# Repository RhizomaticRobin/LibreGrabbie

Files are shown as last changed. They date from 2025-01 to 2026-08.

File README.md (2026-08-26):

# DEXIGRAB

**/ˈdɛk.si.ɡræb/ (DEK-see-grab) - DEXIGRABs (plural): /ˈdɛk.si.ɡræbz/ (DEK-see-grabz)

An advanced, libre-source robot hand with integrated hybrid soft robotics, and soon GelSense-touch capabilities with pretrained sensor fusion RL models

robot hand
robot_hand_back

## Introduction

"What? Another esoteric 3D printed robot hand project that's basically just a toy/puppet/useless gizmo dohicky with 5 string motors? No! There's too many of those already!"

Well, here's where I might change your mind regarding that!

## Features

- **Flexible TPU palm mechanics**, allowing for hybrid soft robotics that allow for actual grasping around curved objects in comparison to current traditional robotic palm mechanics
- 16 motors allowing for **16 DOF hand dexerity**, 3 DOF for each finger and 4 DOF on the thumb
- Straightforward 3D printing and assembly with **only 5-10 3D printed parts** to be assembled together for more plug-and-play use dynamics
- Mechanics and electronics **entirely constrained** inside the palm, allowing for full end-effector modularity with all current and future robotic manipulators
- To utilize a modified L3-F-TOUCH sensing module for the fingers and palm and a stereo raspberry pi camera system for sensor fusion data to train reliable deep reinforcement learning 
- **Universal Robot Attachment** system that can be 3D printed to interface with any robot arm's end effector attachment system
- **Multi-modal sensor fusion** integrating:
  - Intel® RealSense™ Depth Camera D455
  - L3-F-TOUCH sensing for tactile feedback
  - Arduino Pro Mini for motor encoder data collection

## AI & Simulation

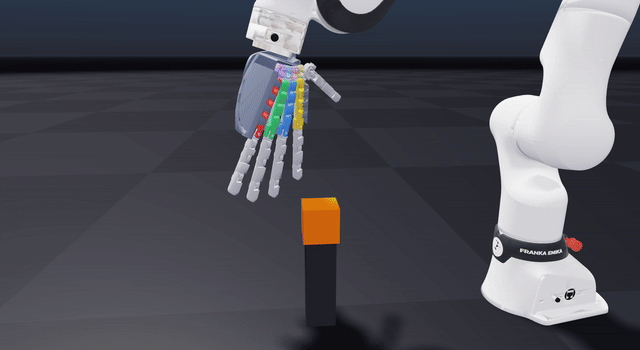
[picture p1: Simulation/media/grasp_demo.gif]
simulated reach -> grasp -> lift with tactile pads


The simulation work now lives in this repo — see [`Simulation/`](Simulation/):

- **Full physics model of the hand in NVIDIA Newton** (MuJoCo-Warp solver): the flexible
  TPU palm modeled as 8 spring palm bones with 3 closed kinematic loops, 22 finger DOFs,
  self-colliding shells, and **15-pad tactile sensing**
- **Arm-mounted grasp demo** (Franka FR3) with an honest `--check` gate — a pass requires a
  clean approach, multi-pad tactile contact, and a real lift, not a cube wedged in the shell
- **GPU-batched in-hand reorientation RL environment** + self-contained PPO trainer,
  validated at **N=8192 parallel worlds, 0.0% solver divergence, ~47k env-steps/s** on a
  single RTX 5090 — plus the full forensics of the batched-solver NaN failure mode that had
  to be root-caused to get there
- **Honest RL status**: reorientation policies stall for contact-fidelity reasons documented
  in [`Simulation/README.md`](Simulation/README.md), so no pretrained models are published
  yet — that finding is what redirected this project toward engine-level contact-physics
  work, rather than shipping policies from a sim that can't be trusted

## Related Resources

- [L3-F-TOUCH shown](https://youtu.be/ASt3WRFcAxU?si=XV7Dn4dw2RqogxgP)
- [General Concept of touch module](https://youtu.be/qtQ4rK66vlE?si=lcGbKkfz59pFsFFY)
- [Simulation environment to be possibly integrated](https://github.com/facebookresearch/tacto)

## Applications

- Primary use as a **robotic end effector** with advanced grasping capabilities
- Secondary application as a **low-weight and cost-accessible hand for prosthetics design**, especially if built with worm drive gearboxes for human-level gripping strength
- Customizable socket system (hopefully also full copyleft) for any given person

## Project Details

- **<$500 cost to build**
- **Fully open source hardware and software** under the GPL 3.0 and CERN-OHL pair license :)

## Coming Soon^TM

- Assembly instructions
- Component lists
- Software setup guide
- Simulation integration details
- Attachment system designs

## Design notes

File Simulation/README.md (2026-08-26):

# Simulation

The DEXIGRAB physics-simulation line: the hand rebuilt as a full articulated model in
[Newton](https://github.com/newton-physics/newton) (NVIDIA's GPU physics engine, MuJoCo-Warp
solver) — flexible palm mechanism and all — with per-pad tactile sensing, an arm-mounted
grasp demo, and a GPU-batched in-hand reorientation RL environment.

reach -> whole-hand grasp -> lift, palm-side view with the 15 tactile pads

*The arm-mounted demo: reach, whole-hand grasp, lift — recorded straight from `newton/flexpalm_arm_demo.py --arm franka --viewer gl` (full quality: [media/grasp_demo.mp4](media/grasp_demo.mp4)).*

This is the simulation work the main README used to promise as "upcoming". It's here now,
including the parts that didn't go the way I wanted (see *Honest status* below).

## What's in here

| Path | What it is |
|---|---|
| [`newton/`](newton/) | All code. Start with [`newton/README.md`](newton/README.md) (hand model + arm grasp demo) and [`newton/README_reorient.md`](newton/README_reorient.md) (batched RL env + the solver-stability findings). |
| [`assets/`](assets/) | The hand CAD as USD (same geometry as `Hardware/`, exported for sim) + the Shell2 recovery re-export. |

Highlights:

- **The hand as a real mechanism, not a rigid prop**: 8 spherical-jointed palm bones with
  tuned spring/damping (the flexible TPU palm), 3 closed kinematic loops, 22 finger DOFs,
  convex-decomposed self-colliding shells.
- **`flexpalm_arm_demo.py`** — reach → whole-hand grasp → lift of a cube on a Franka FR3
  flange, with a 15-pad tactile heatmap. Its `--check` gate only passes a **real grasp**:
  clean approach (the open hand must descend *around* the cube, not through it) + tactile
  contact on ≥2 pads + a >2 cm lift. Lift-only checks are a trap — they green-light a cube
  wedged inside the shell.
- **`flexpalm_reorient_env.py`** — Allegro-style in-hand cube reorientation, GPU-batched
  (one model, one solver, N worlds), 102-D obs including the 15 tactile pad forces,
  validated at **N=8192 with 0.0% solver divergence at ~47k env-steps/s** on one RTX 5090.
- **`train_reorient.py`** — self-contained GPU PPO on that env (rsl_rl `VecEnv`-compatible).
- **`stress_reorient.py`** — the NaN-localization harness that found the solver failure
  modes documented in `README_reorient.md`.

## Requirements

An NVIDIA GPU + a Python env with `newton` (verified on **1.4.0**; the 1.2-era equality API
this was written against is restored by the tiny [`newton/newton_compat.py`](newton/newton_compat.py)
shim), `warp-lang`, `torch`, `usd-core`, `numpy`. Verified on an RTX 5090.

## Honest status

- **What stands**: the mechanism sim, the tactile sensor, the honest-gated grasp demo, and a
  batched env that is *stable at scale* — getting there took root-causing a real solver
  failure (the batched contact + equality solve diverged to NaN in a growing fraction of
  worlds past N≈8; the full forensics, the fix, and the measured tables are in
  [`newton/README_reorient.md`](newton/README_reorient.md)).
- **What didn't work**: dexterous reorientation *policies*. Training runs stall for reasons
  that trace to contact fidelity, not hyperparameters — so no pretrained models are
  published, and I'm not going to ship a policy that only works in a sim I don't trust.
  That result is what pushed this project down the stack, into engine-level work on contact
  physics faithful enough that soft-hand policies trained in sim mean something.

Same licenses as the rest of the repo (GPL-3.0 code; the CAD-derived assets follow the
hardware license).

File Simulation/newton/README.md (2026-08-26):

# flexpalm_hand — flexible robot hand on a Franka *or* Dorna 2 arm (Newton)

A semi-flexible 3D-printed robot hand (8 spherical-jointed palm bones, 5 fingers, convex-
decomposed shell with self-collision) **mounted on a robot arm flange**, performing a
**reach → whole-hand grasp → lift** of a cube, with **per-pad tactile sensing shown as an
in-viewer fingertip heatmap**. Pure Newton + `SolverMuJoCo`, runs in the `isaac` conda env.

Two arms, selected with `--arm` (same hand, mount, grasp logic and tactile for both):
- **`franka`** (default) — Franka FR3 via `add_urdf`.
- **`dorna`** — a **Dorna 2** (5-DOF) with hollow-6xxx-aluminum mass/inertia tuned to the
  real **5.5 kg** arm weight. The Dorna CAD conversion is **not redistributed** in this repo
  (third-party CAD); point `DEXIGRAB_DORNA_USD` at your own USD conversion to enable it.

## Run

```bash
cd Simulation/newton
export LD_LIBRARY_PATH="$CONDA_PREFIX/lib/python3.12/site-packages/nvidia/cu13/lib:${LD_LIBRARY_PATH:-}"   # tactile kernel NVRTC JIT
# headless gate: finalize + reach/grasp/lift, asserts a REAL grasp (clean approach + contact + lift)
python flexpalm_arm_demo.py --arm franka --check
# interactive GL viewer. The viewer steps the full schedule.
python flexpalm_arm_demo.py --arm franka --viewer gl
```

The viewer steps a heavy model (56 bodies, MuJoCo solver + per-frame tactile) at ~0.3x
real-time, so the reach→grasp→lift sequence plays out over a few seconds of wall-clock after
the window opens, then holds the lifted cube.

## Files

| File | Role |
|---|---|
| `flexpalm_arm_demo.py` | **The demo.** Builds the arm (`--arm`) + welds the hand to the flange + a graspable cube on a pedestal; scripted reach/grasp/lift schedule; tactile heatmap recolor; `--check` honest gate. `--viewer gl`. |
| `arms.py` | **Arm builders.** `build_franka` / `build_dorna` → an `ArmSpec` (flange, dofs, ready pose, lift dofs, cube/pedestal defaults). For the Dorna: imports the USD, **re-roots** the articulation at the base (it imports rooted at the flange — inverted), and applies **hollow-aluminum mass/inertia** (`compute_inertia_mesh`, ρ=2700, wall thickness solved for 5.5 kg total). `GRASP_POCKET` + `flange_world_at_ready` place the cube in the hand's rigid rest frame so the grasp transfers between arms. |
| `flexpalm_bones4.py` | The hand builder (`Example`). Body/joint/shell/strip wiring, CoACD self-collision, pose battery. Embeddable: `Example(viewer, args, ext_builder=, attach_body=, attach_xform=, finalize=False)`. Standalone `--viewer gl`/`--check` still work. |
| `hand_taxels_newton.py` | `HandTaxelSensor` — standalone-Newton port of the IsaacLab `_hand_taxels.py` taxel sensor; rasterizes MJWarp per-contact data into per-pad normal force. |
| `franka_show.py` | Helper: spawn the Isaac Franka (Panda) arm in the Kit/PhysX viewer to inspect the flange (run from an IsaacLab checkout: `./isaaclab.sh -p franka_show.py`). |
| `robot_hand_poses.py` | **Vendored** pose battery (`CHAINS`, `JointLookup`, `build_poses`, ...; numpy-only). Copy of the IsaacLab demos file, kept here so the demo is self-contained. `flexpalm_bones4` prefers this local copy. |
| `flexpalm.py`, `flexpalm_spheres.py`, `probe_*.py` | Earlier scaffolding / geometry probes (kept for reference). |

## Assets

- The hand geometry ships in [`../assets/`](../assets): `robot_hand_flexpalm.usda` (working
  copy the builder loads), `robot_hand_simready.usda` (untouched original — the palm cover
  strips are read from here), and the Shell2 recovery re-export. Override the asset root with
  `DEXIGRAB_ASSETS`. The Dorna 2 arm USD is **not** included (see above).

## How the demo works

- **Mount (mechanical mate):** the hand's `cover_back` backplate (at the hand's −X wrist end,
  measured plate normal/center baked into `COVER_BACK_NORMAL`/`COVER_BACK_CENTER`) is seated
  **flat and centered** on the flange face, fingers extending down the tool axis. Computed
  purely in the flange-local frame, so it's independent of the arm pose.
- **Reach → grasp → lift:** arm starts poised above, descends onto the cube, the fingers +
  thumb close on it at the digit **convergence point**, then the shoulder (joint 1) raises to
  lift the cube off the pedestal. A free cube + pedestal keeps grasp forces bounded (stable).
- **Tactile:** `HandTaxelSensor.update()` each frame; `model.shape_color` is rewritten so each
  pad ramps from its base color → yellow → red by contact force (`--force-max` is the
  saturation force).

## Key CLI knobs

`--cube <half_m>` `--cubex/--cubey/--cubez` (cube size/pos — default 6 cm at the finger/thumb
convergence so the **thumb is required**), `--cube-density`, `--grasp-max` (close fraction /
grip firmness), `--force-max` (heatmap saturation N), `--mrz` (palm spin about the wrist axis),
`--mdx/--mdy/--mdz` (seat nudge), `--substeps`/`--iters` (sim speed vs accuracy).

Schedule timing is in `Example._schedule` via `getattr` (settle / approach_dur / close_dur /
hold_dur / lift_dur / lift_amt) — edit there to retune the choreography.

## How the cube is placed (and why the grasp transfers between arms)

The mount mate's shortest-arc rotation lands the hand at a **different roll about the tool axis**
on each flange, so a cube placed at a fixed *flange-local* offset ends up in a different spot
relative to the *hand* — on the Dorna it lands under the palm and gets swallowed. Instead the cube
is placed in the hand's **rigid rest frame** `flange ∘ mount` at a universal `GRASP_POCKET`
derived from the working Franka grasp. That reproduces the same hand-relative grasp on any arm.

For the Dorna, lifting via a single revolute (`dof2`) rotates the hand as it moves, so the
**approach** uses a *small* `lift_amt` (near-vertical, so the open hand descends cleanly **around**
the cube) and the **final lift** uses a larger `lift_raise` (the cube is enclosed by then, so the
tilt is harmless). This is the difference between a real grasp and a cube wedged inside the shell.

## Verified — honest `--check` gate (RTX 5090, `isaac` env, Newton 1.2.0)

`--check` asserts a **REAL GRASP = clean approach + contact + lift**, where:
- **clean approach**: with the hand forced *open*, the descending hand disturbs the resting cube
  by <1.5 cm (i.e. it descends *around* the cube, not *through* it — guards against the cube being
  swallowed by / wedged inside the shell, which a lift-only check cannot see);
- **contact**: tactile fires on ≥2 pads; **lift**: the cube rises >2 cm from grasp to end.

| Arm | mass | approach disturbance | pads (thumb) | cube lifted | REAL GRASP |
|---|---|---|---|---|---|
| `franka` | — | 0 mm | 6 (yes) | +160 mm | **PASS** |
| `dorna` | 5.50 kg (hollow Al, 2.9 mm wall) | 8 mm | 9 (yes) | +129 mm | **PASS** |

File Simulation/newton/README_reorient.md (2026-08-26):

# flexpalm in-hand cube reorientation — batched-Newton RL env

An **Allegro-style in-hand reorientation task** driven by the flexible flexpalm hand **+ its
15-pad tactile sensor**: the hand is fixed palm-up, cradles a free cube, and the policy moves the
22 finger DOFs (PD position targets) to rotate the cube to a randomly sampled target orientation.
Pure Newton + `SolverMuJoCo`, **GPU-batched over N worlds** in one model/one solver, `isaac` env.

Mirrors IsaacLab's `InHandManipulationEnv` (random-quat goal, rotation-distance reward,
success / consecutive-success goal resampling, drop termination) but with our underactuated
closed-loop hand instead of a fully-actuated Allegro/Shadow hand.

## Run

```bash
cd Simulation/newton
export LD_LIBRARY_PATH="$CONDA_PREFIX/lib/python3.12/site-packages/nvidia/cu13/lib"   # tactile NVRTC JIT
python flexpalm_reorient_env.py --check --num-envs 64        # env gate (finite, cube seats, tactile fires)
python stress_reorient.py --mode all --num-envs 1            # solver stress / NaN-localization harness
python train_reorient.py --num-envs 256 --iters 2000         # self-contained GPU PPO
```

## Files
| File | Role |
|---|---|
| `flexpalm_reorient_env.py` | `FlexPalmReorientEnv` — batched build, palm-up cube seating, 22-DOF residual action, 102-dim obs (incl. 15 tactile pad forces), rotation-distance reward, goal resampling, drop termination, NaN-guarded rsl_rl-style VecEnv. `--check` gate. |
| `train_reorient.py` | Self-contained GPU PPO (actor-critic MLP). Env also satisfies the rsl_rl `VecEnv` protocol + returns `{"policy": obs}` from `reset()`, so it drops into rsl_rl `OnPolicyRunner` or liquid-NN `CfCPPO` with no adapter. |
| `stress_reorient.py` | Stress/NaN-localization harness — applies external "tug" wrenches + max-rate finger slew, steps substep-by-substep, reports the first non-finite body/joint + run-up. |
| `hand_taxels_newton.py` | `HandTaxelSensor` — now **batched** (`pad_total[N,15]`, indexed by `con_worldid`); N=1 keeps the original single-world behavior. |
| `flexpalm_bones4.py` | The hand builder (unchanged mechanism); added `simple_shells` collision option (see below). |

## Observation / action / reward

- **obs (102)**: finger pos (unscaled) 22 · finger vel×0.2 22 · cube pos3/quat4/linvel3/angvel3 13 ·
  goal quat 4 · relative quat 4 · **tactile pad forces 15** · prev action 22.
- **action (22)** ∈ [-1,1]: a *residual around the cupped hold pose* (a=0 holds the cube; a=±1 →
  ±0.35 rad), so the stiff hand stays stable and learning starts from a working grasp.
- **reward**: `1/(|rot_dist|+0.1) − 10·goal_dist − 2e-4·Σa² + 250·[rot_dist≤tol] − 50·[dropped]`,
  `rot_dist = 2·asin(‖vec(q_obj·conj(q_goal))‖)`. Consecutive success resamples the goal without
  ending the episode; terminate on drop or timeout.

## The real NaN root cause: the equality SOLVE (use `soft_loops`)

**The definitive fix.** The mitigations below (`shells_jointed`, buffer sizing, substeps, the
NaN-reset guard) reduced but never eliminated the divergence — a long N=8192 run still crept to
~28–31% NaN and collapsed reward. The actual root cause is the **4 MuJoCo equality constraints**
(3 loop closures + shell weld): the equality solve ill-conditions under contact + exploration and
diverges. **`soft_loops=True`** removes all 4 and closes the loops with explicit **penalty-spring
forces** on `body_f` each substep (a Warp kernel between body-local anchors), staying on
SolverMuJoCo (tactile + CUDA graph intact):

| config (N=8192) | env-steps/s | long-run NaN | reward |
|---|---|---|---|
| equality, substeps=4 | 16.8k | **collapsed → 31%** | −4 → −21 |
| equality, substeps=8 | 16k | **crept → 28%** | flat/creep |
| **`soft_loops`, substeps=8** | **47k** | **0.00% (flat, 200 iters)** | −4.7 → −3.2 ✓ |

Removing the equality solve **both eliminates the NaN and runs ~3× faster** (no constraint solve).
Requires **substeps=8**: at substeps=4 the larger dt blows up the explicit springs (NaN → 62%) — an
explicit-integration limit on the light connector proxies. This is now the **trainer default**
(`--soft-loops`, on by default; `--hard-loops` selects the old equality path). Gains
`LOOP_SPRING_KE/KD/FMAX` (1e4 / 1e2 / 300). Convention note: Newton `body_f` is `[force, torque]`
and `body_qd` is `[linear, angular]` — get either wrong and the wrench pumps energy and blows up.

*(A `solver="kamino"` path was attempted — maximal-coordinate, implicit springs — but is **blocked**:
the Newton→kamino `from_newton` bridge can't represent closed loops. Scaffolding kept but inert.)*

## The high-N stability fix (earlier mitigations — superseded by soft_loops as the cure)

The hand is **underactuated + closed-loop + shelled** — unlike the fully-actuated tree-hands
(Allegro/Shadow) the in-hand task was built for. Replicated naively, mujoco-warp's **batched
contact solve diverged to NaN in a growing fraction of worlds above ~8** (N=8 clean, N=256 ~50%).
Ruled out by stress-testing: buffer sizing (real but secondary bugs, fixed), solver config
(Allegro's settings were *worse*), a velocity watchdog (divergence is instantaneous, not a
runaway), and `SolverKamino` (rejects equality constraints → can't run our closed loops). The hand
*alone* was stable at N=256; **the cube vs the hand's ~108 convex collision parts** was the trigger.

**Fix — `shells_jointed` (default ON for this env):** keep the back/bottom shells as **full-
resolution VISUAL meshes** (topology preserved — no convex-blob hack) but take them **out of
collision entirely**, and connect **Shell1↔Shell2 with one explicit equality constraint** — the
chassis hinge the design implied, made explicit so the contact solver never has to mediate the
shells. The shells are the outer chassis (never touch the cube, already self-filtered), so collision
was only ever a liability. **Fingers + palm bones keep full collision (grasp + tactile), visuals are
unchanged, and the underactuated mechanism — D6 spring palm bones, 3 closed loops, 22 finger
revolutes — is untouched.** (`simple_shells`, collapsing each shell to one convex hull, is the
earlier superseded variant; still available.)

**The joint is a CALIBRATED compliant WELD, not a free ball.** A free `connect` (ball-and-socket)
pivots too loosely — it leaves a **27° rotation gap** vs how the shells actually move under the
prior full-CoACD collision. So Shell1↔Shell2 is a `weld` (constrains position **and** orientation,
`torquescale` weighting rotation, `eq_solref` the compliance), and its 5 free parameters — ball
**center (3)** + **torquescale** + **solref time-constant** — are fit to match the reference
CoACD-collision shell trajectory. The fit is done **batched on the GPU**
(`calibrate_shell_ball.py --batched`): each of N worlds gets a *different* candidate weld
(heterogeneous `begin_world`/`add_builder` build), one rollout scores the whole population, and an
evolutionary loop tightens around the elites — **~49k candidates (pop 4096 × 12 gens)** in minutes.

The pivot is **pinned to the shells' fitted mating-sphere center** (where they physically
articulate) by a geometric regularizer (`SHELL_REG=1.0`), then torquescale + solref are fit to the
trajectory: center `(-0.1206, -0.0298, -0.0082)`, torquescale `0.50`, solref_tc `0.099` →
**pos 15 mm / rot 13.5°** against the reference's own ~38 mm shell drift. (Letting the center float
free reaches **5.9 mm / 5.5°** but parks the pivot ~85 mm off the mating surface; we chose the
physically-placed pivot — still far better than the free ball's 27° rotation gap. Drop `SHELL_REG`
to recover the unconstrained fit.)

**Substeps depends on the weld stiffness.** A *stiff* weld (the unconstrained `torquescale 1.54`
fit) needs `substeps=8`: at `substeps=4` it leaves ~8% of worlds diverging under a worst-case probe,
masked by the NaN guard. The **chosen geometric weld is softer (`torquescale 0.50`)** and tolerates
`substeps=4` — only ~0.1% diverge worst-case at N=8192 (5/8192), and PPO trains healthy. The env
class still **defaults to `substeps=8`** (conservative for `--check`/eval and any future stiffer
weld), but **the trainer defaults to `substeps=4`** (the validated, 2×-faster training config).

Also kept as defenses: contact/triangle-pair buffers sized to world count, a NaN-reset guard
(diverged world → `NAN_PENALTY` + reset, logged), a finite-guarded optimizer step (a non-finite
loss/grad never reaches the weights — can't collapse the policy), and a velocity watchdog.

## Scaling + substeps frontier (RTX 5090, short-PPO sweep, geometric weld)

`HEALTHY` = reward improves + max-NaN < 15% + no collapse; `BROKEN` = reward collapsed / NaN runaway.

| N | substeps | tri-pairs/world | max NaN% | env-steps/s | VRAM | verdict |
|---|---|---|---|---|---|---|
| 512 | **2** | 80k | 30.5% | 5323 | — | **BROKEN** (reward → −22) |
| 512 | 4 | 80k | 1.2% | 2749 | — | HEALTHY |
| 512 | 6 | 80k | 1.4% | 2189 | — | HEALTHY |
| 512 | 8 | 80k | 0.0% | 2058 | — | HEALTHY (cleanest) |
| 2048 | 4 | 30k | 2.3% | 5809 | — | HEALTHY |
| 4096 | 4 | 30k | 2.6% | 7207 | 10.8 GB | HEALTHY |
| **8192** | **4** | **15k** | **~2%** | **11083** | **12.4 GB** | **HEALTHY ← default** |
| 4096 | 8 | 30k | 0.03% | 3905 | — | HEALTHY |
| 8192 | 8 | 15k | 0.07% | 5719 | — | HEALTHY |

**Read-off:** substeps floor is **4** (2 collapses); N scales to **8192** with no stability cost
(per-world divergence is N-independent — NaN% stays ~2% regardless of N) and throughput keeps rising
(11k env-steps/s at N=8192/s4). N=8192 fits in **12.4 GB** of 32 GB, but **N=16384 OOM'd** even at
8k tri-pairs/world (one internal buffer alone wanted 11.4 GB) — so 8192 is the practical ceiling at
these buffer sizes; past it needs a different broad-phase strategy (self-pair exclusion), not just a
leaner buffer. (**Superseded:** this frontier was measured on the *equality* path, whose s4 "winner"
actually collapses long-run — see the soft_loops section above; the real winner is `soft_loops`,
substeps=8, ~47k env-steps/s, 0% NaN.) **Equality-path winner: N=8192, substeps=4** — ~2× the substeps=8 throughput, NaN held ~2% by the
guards, training healthy.

**CUDA-graph capture (default on, `use_graph=True`).** The substep physics loop (`_step_sim`:
collide → solver.step → swap → Warp-kernel velocity watchdog — ~90% of per-step launches) is
captured once into a `wp.ScopedCapture` graph and replayed, killing per-launch + Python-loop
overhead. At N=8192/s4: **11.4k → 16.6k env-steps/s (1.46×)**, correct (graph-vs-eager divergence ≤
the eager-vs-eager atomic-nondeterminism baseline) and NaN-rate-neutral. Capturable because the loop
is Warp-only (the watchdog is a Warp kernel, not `torch.clamp_`); reward/done/NaN-guard/reset stay
eager (host syncs, ~10% of launches). Requires **even substeps** (the double-buffer ping-pong lines
up); odd substeps or any capture failure fall back to eager with a **loud banner** — never silent.

## Verified (RTX 5090, isaac, Newton 1.2.0 / mujoco-warp 3.8)

- `--check` N=64: finite, cube seats palm-up at the cup, tactile fires (all envs), cube held under
  random actions, REAL-grasp gate PASS.
- **Stability (`shells_jointed` weld, substeps=8):** N=256 `--check` PASS (finite, peak pad force
  finite — no masked NaN, cube held 98%); worst-case stress probe (uniform-random action/step)
  **0.4% diverged at N=256, 0.2% at N=512** (vs `simple_shells` 2.7%), handled by the reset guard.
  `simple_shells` alone: **N=16…2048 → 0% NaN** under the gentler `--check` actions, held 97–100%.
- **Throughput** (substeps=8): ~1,400 env-steps/s at N=256; scales with N. VRAM ~3 GB at N=256,
  ~14.6 GB at N=2048 (`simple_shells`); the triangle-pair broad-phase buffer is the VRAM bottleneck
  (`_tripairs_per_world` — lean 30k fits N=4096). The batched weld calibration runs pop=4096 at
  ~17 GB.
- **Profiling** (N=2048): the step is ~100% physics — **collision detection ~77%, solver ~23%**,
  everything else (tactile, obs, reward, reset) <0.5% combined. Both run per substep, so substeps is
  the main speed knob — but the calibrated weld needs 8 for stability (see above), so substeps is not
  free here. The remaining big lever is cutting collision broad-phase work (excluding hand-self
  candidate pairs / lower-vert finger hulls).
- **Training: PPO learns** — in the first iterations the drop rate falls and reward rises as the
  policy learns to hold + manipulate the cube. Full reorientation (success rate up) needs long runs,
  as for any in-hand task.

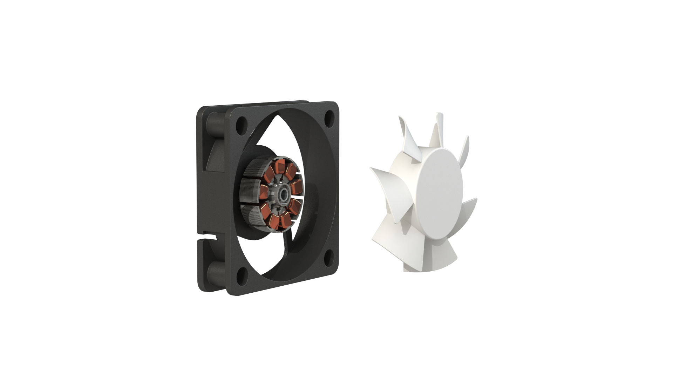
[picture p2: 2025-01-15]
Hardware/Biomemetic Robot Hand, Prosthetic/MiniFan/Renderings/Exploded.png

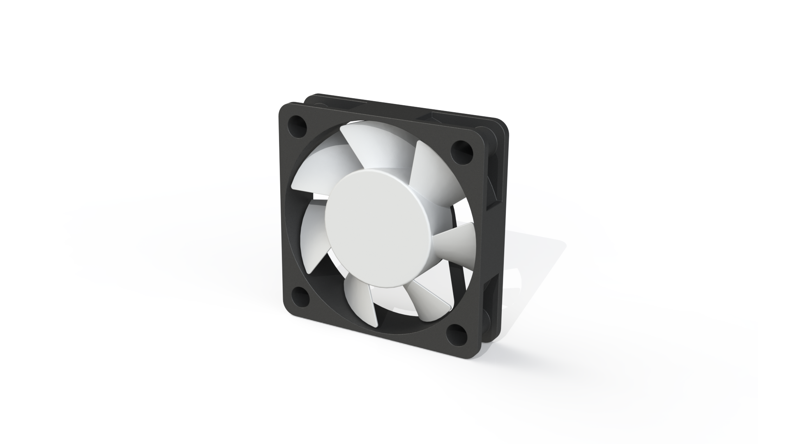
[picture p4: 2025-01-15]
Hardware/Biomemetic Robot Hand, Prosthetic/MiniFan/Renderings/TiltedIsometric.png

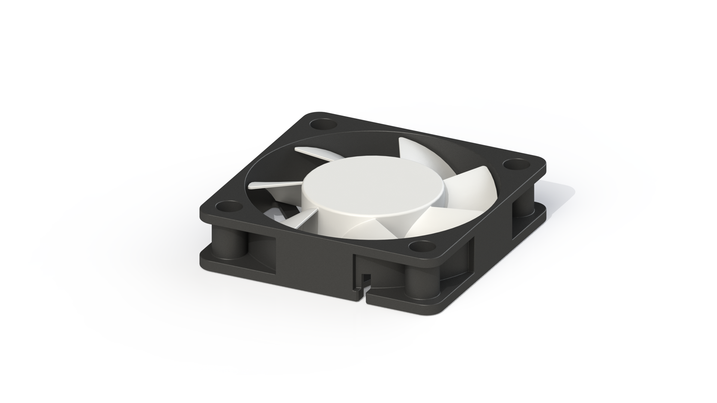
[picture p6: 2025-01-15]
Hardware/Biomemetic Robot Hand, Prosthetic/MiniFan/Renderings/Resting.png

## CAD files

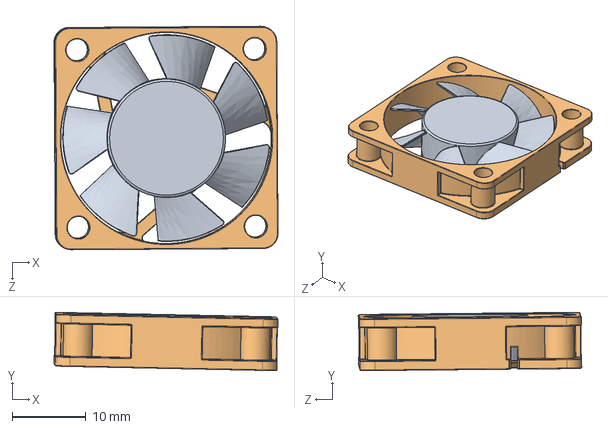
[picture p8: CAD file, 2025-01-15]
Hardware/Biomemetic Robot Hand, Prosthetic/MiniFan/final_assembly.SLDASM
30.3 x 7.87 x 30.2 mm
RotorBlades
MotorHouse

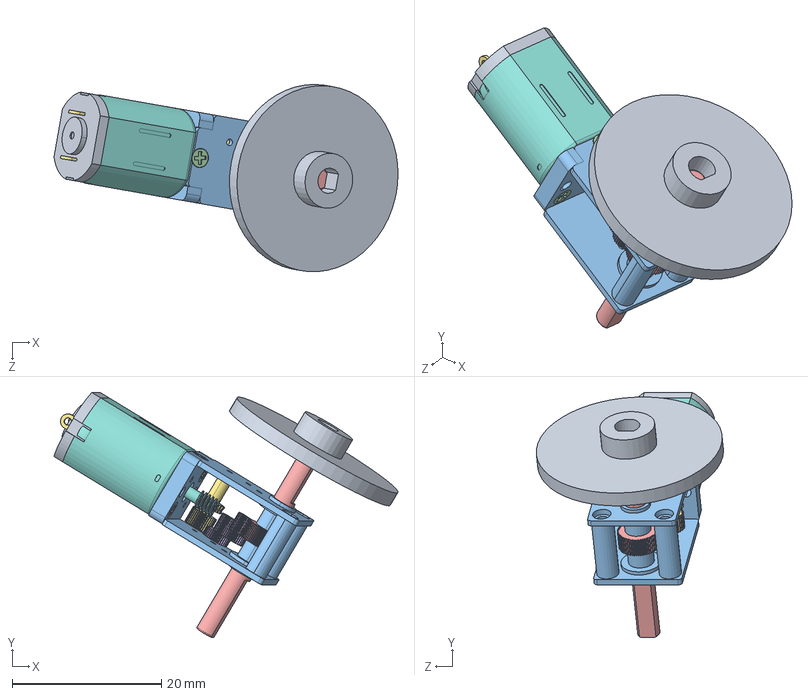
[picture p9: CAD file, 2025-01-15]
Hardware/Biomemetic Robot Hand, Prosthetic/Assem1.SLDASM
46.1 x 32.8 x 25.1 mm
____________.STEP
____.STEP
______.STEP
____-0.STEP
__________.STEP
____-1.STEP
____-2.STEP x 2
________.STEP
__.STEP
________-3.STEP
__________-4.STEP
____________-5.STEP x 4
Engrenagem reta28-D.STEP
Engrenagem reta22-11.STEP x 2
WHEEL.STEP
WORM.STEP
hand_pulley_wheel1

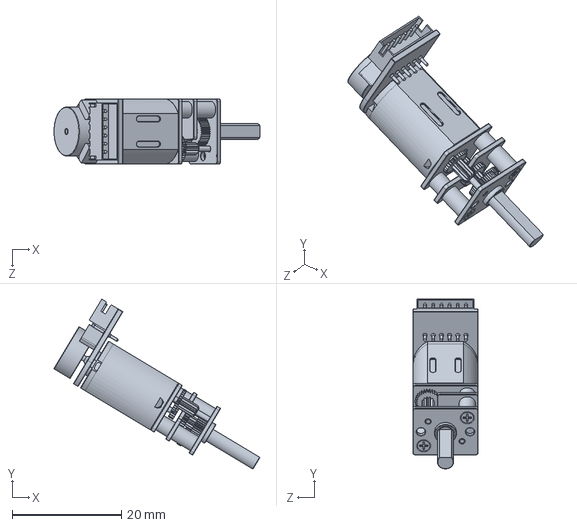
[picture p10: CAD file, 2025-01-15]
Hardware/Biomemetic Robot Hand, Prosthetic/motor_cav.SLDASM
37.8 x 31.1 x 12.0 mm

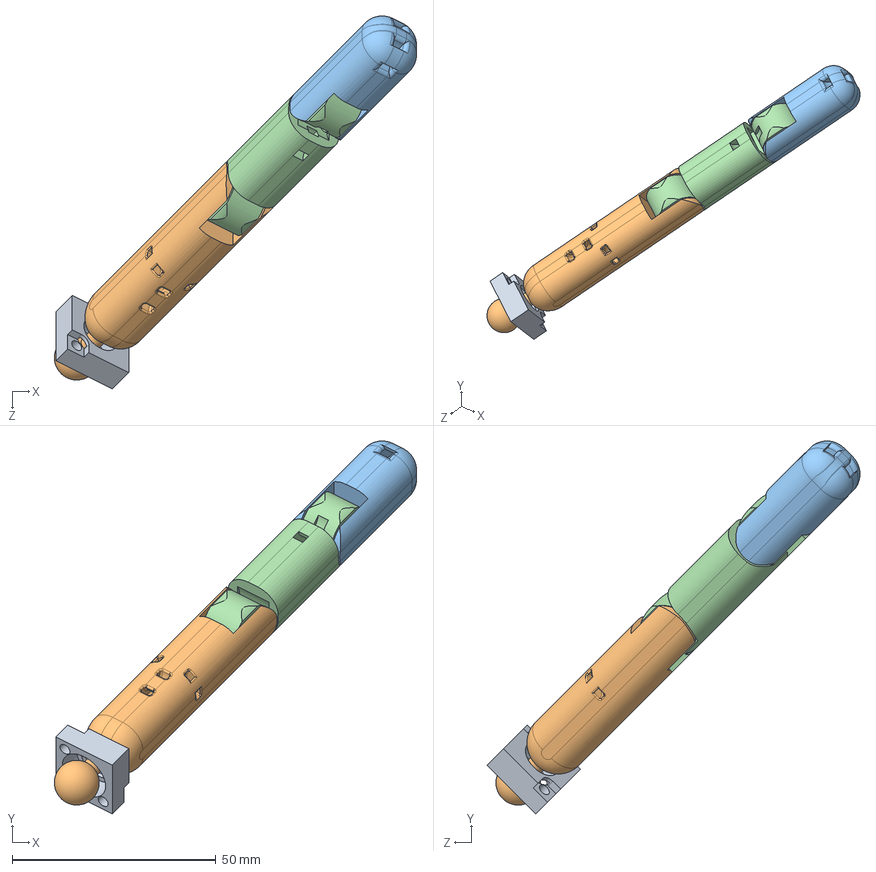
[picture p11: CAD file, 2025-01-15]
Hardware/Biomemetic Robot Hand, Prosthetic/thumb_assembly.SLDASM
88.9 x 91.6 x 91.6 mm
thumb_ball_joint_cap
Metacarpal Bone_V02_thumb
Distal Phalanx Bone_V02
Proximal Phalanx Bone_V02

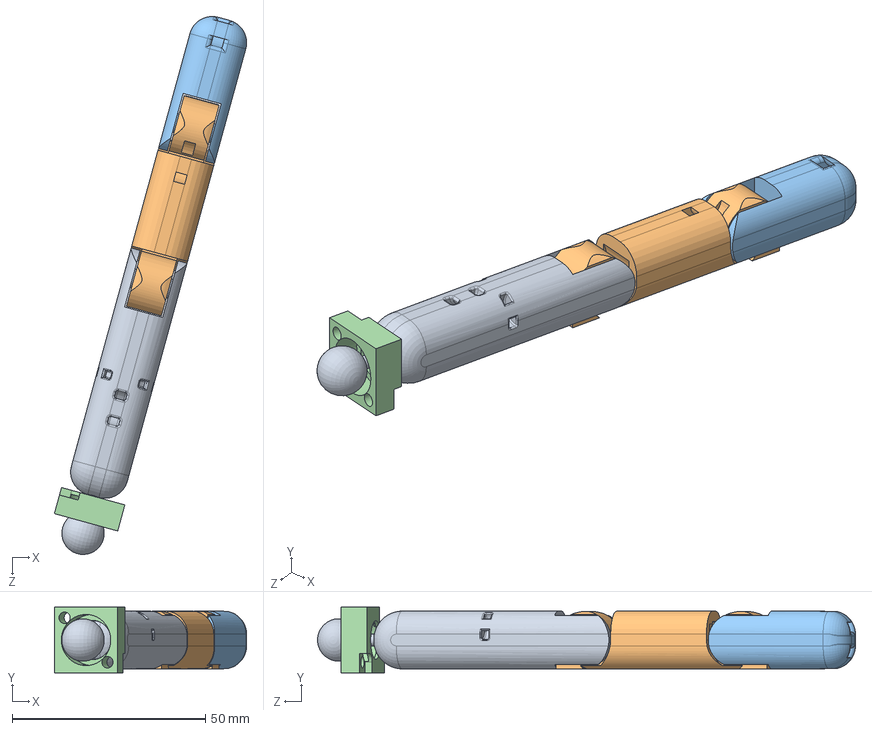
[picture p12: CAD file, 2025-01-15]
Hardware/Biomemetic Robot Hand, Prosthetic/thumb_printable.SLDASM
49.8 x 17.0 x 139.2 mm
Metacarpal Bone_V02_thumb
Proximal Phalanx Bone_V02
Distal Phalanx Bone_V02
thumb_ball_joint_cap

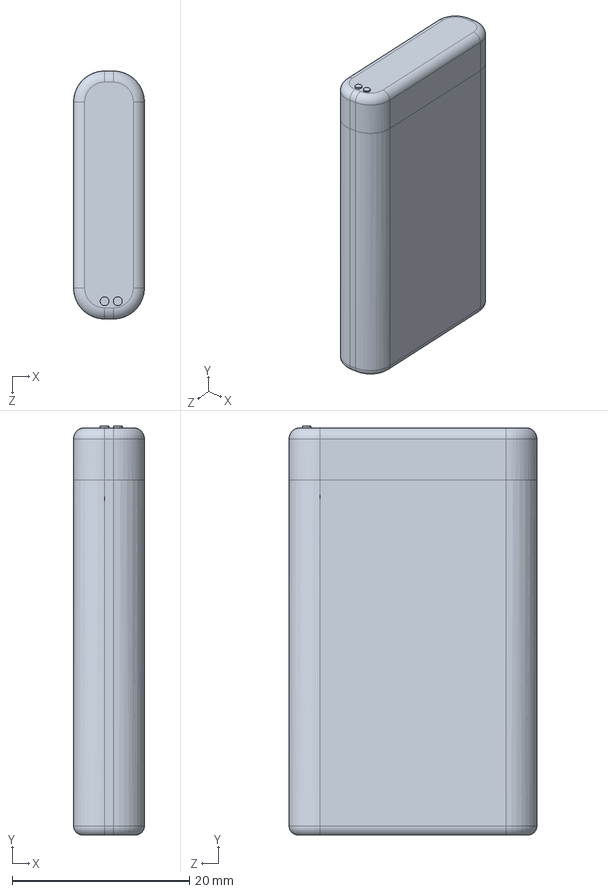
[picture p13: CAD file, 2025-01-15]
Hardware/Biomemetic Robot Hand, Prosthetic/battery_tolerance_shell_ass.SLDASM
8.00 x 46.2 x 28.0 mm

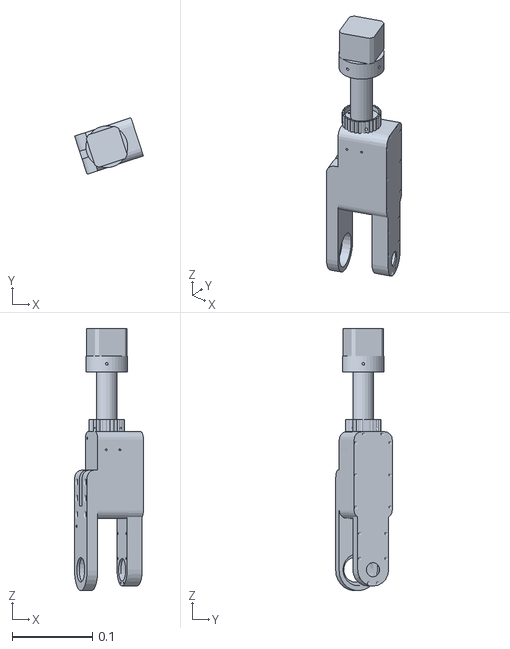
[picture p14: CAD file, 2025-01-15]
Hardware/Biomemetic Robot Hand, Prosthetic/ROS_AR2_urdf-master/meshes/link_4.STL
0.0856 x 0.0704 x 0.326

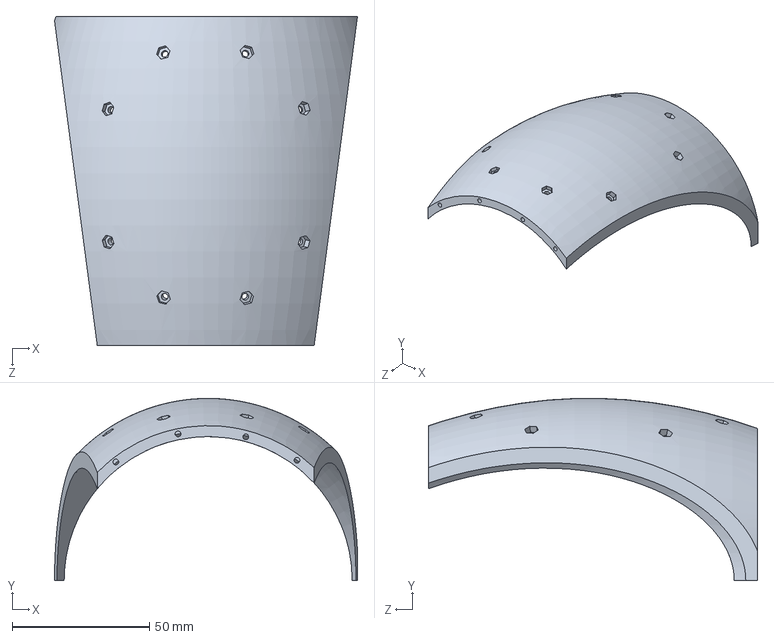
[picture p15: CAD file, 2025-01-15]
Hardware/Biomemetic Robot Hand, Prosthetic/Shell1.SLDPRT
110.5 x 66.4 x 120.0 mm

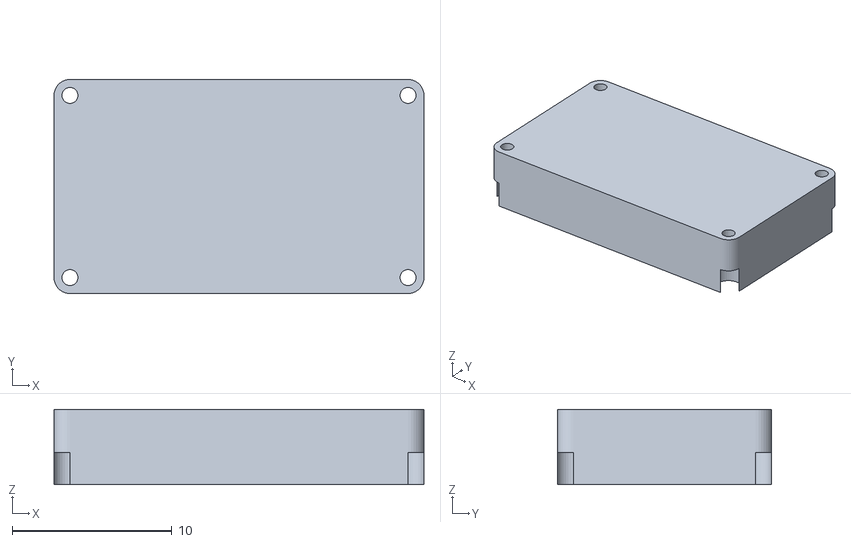
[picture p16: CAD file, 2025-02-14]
L3-F-TOUCH-master/prototype/Acrylicsheet.stl
23.2 x 13.4 x 4.70

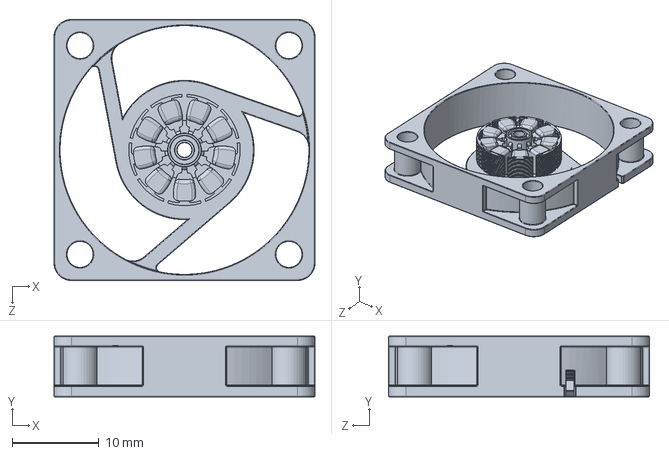
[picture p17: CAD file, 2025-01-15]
Hardware/Biomemetic Robot Hand, Prosthetic/MiniFan/MotorHouse.SLDPRT
30.0 x 7.00 x 30.0 mm

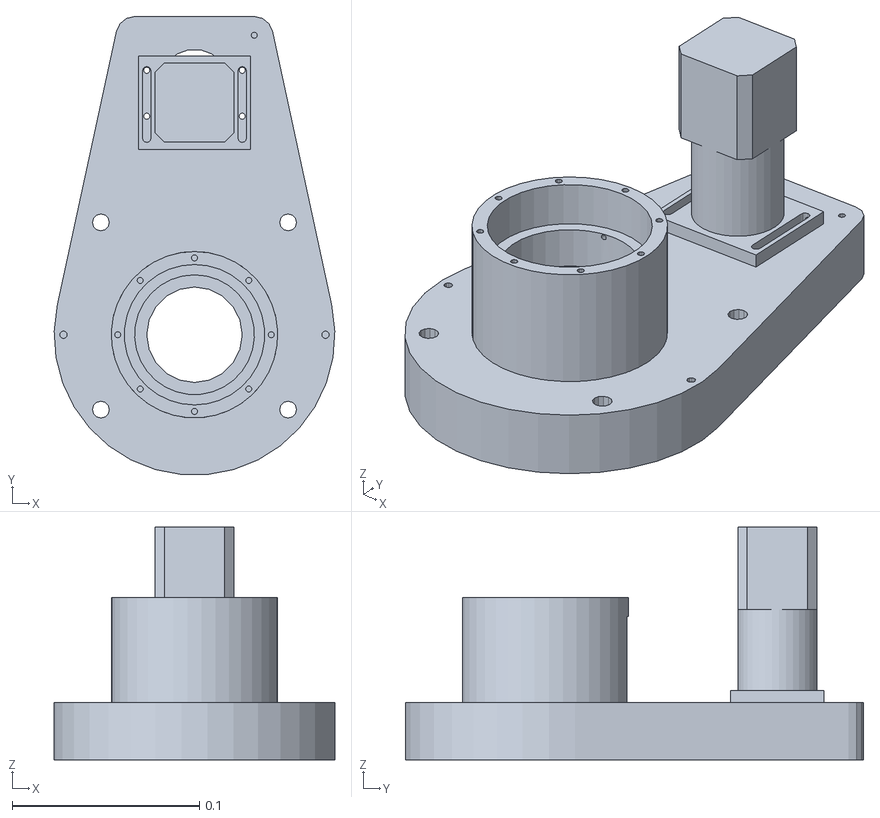
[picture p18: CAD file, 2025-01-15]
Hardware/Biomemetic Robot Hand, Prosthetic/ROS_AR2_urdf-master/meshes/base_link.STL
0.15 x 0.245 x 0.124

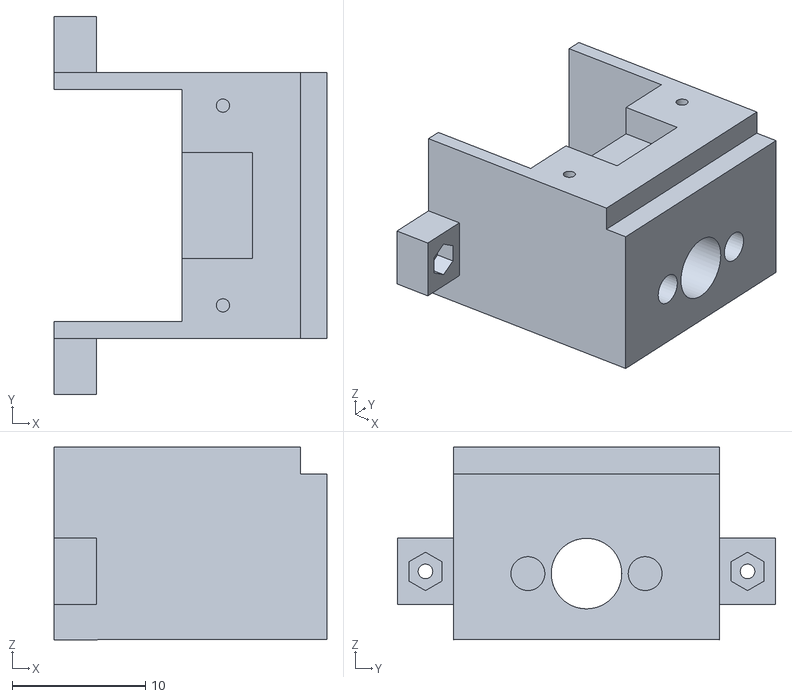
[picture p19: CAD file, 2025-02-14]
L3-F-TOUCH-master/prototype/Bottom2.stl
20.5 x 28.4 x 14.5

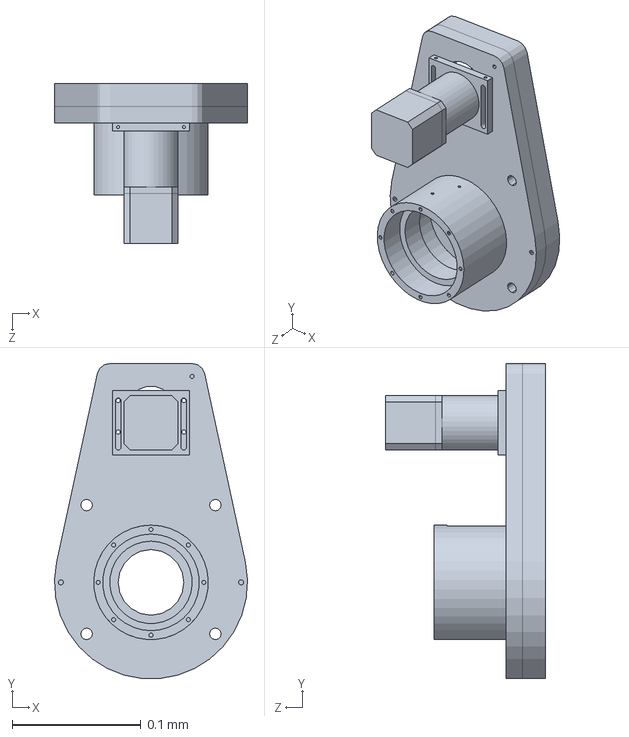
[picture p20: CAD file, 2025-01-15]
Hardware/Biomemetic Robot Hand, Prosthetic/base_link.SLDPRT
0.15 x 0.245 x 0.124 mm

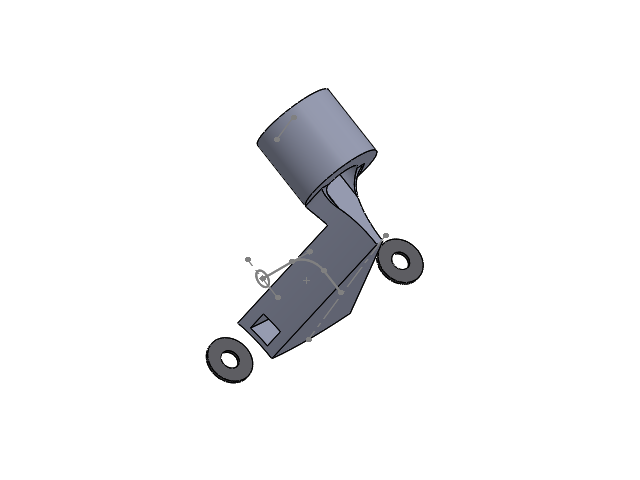
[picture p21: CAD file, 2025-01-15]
Hardware/Biomemetic Robot Hand, Prosthetic/Pulley_long.SLDASM
m1p6washer x 2
hand_pulley_wheel_newcut

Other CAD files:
Hardware/Biomemetic Robot Hand, Prosthetic/Pulley_short.SLDASM
Hardware/Biomemetic Robot Hand, Prosthetic/Thumb.SLDASM
Hardware/Biomemetic Robot Hand, Prosthetic/Assem2.SLDASM
Hardware/Biomemetic Robot Hand, Prosthetic/Battery_case.SLDASM
Hardware/Biomemetic Robot Hand, Prosthetic/1100mAh lipo v8.SLDPRT
Hardware/Biomemetic Robot Hand, Prosthetic/Base Bone 1.2_V02.SLDPRT
Hardware/Biomemetic Robot Hand, Prosthetic/Base Bone 1.2_V02_metacarpal2.SLDPRT
Hardware/Biomemetic Robot Hand, Prosthetic/Base Bone 1.2_V02_metacarpal3.SLDPRT
Hardware/Biomemetic Robot Hand, Prosthetic/Base Bone 1.2_V02_middlefinger.SLDPRT
Hardware/Biomemetic Robot Hand, Prosthetic/Base Bone 1.2_V02_middlefinger_and_thumb_attachment.SLDPRT
Hardware/Biomemetic Robot Hand, Prosthetic/Base Bone 1.2_V02_middlefinger_left.SLDPRT
Hardware/Biomemetic Robot Hand, Prosthetic/Base Bone 1.2_V02_middlefinger_right.SLDPRT
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

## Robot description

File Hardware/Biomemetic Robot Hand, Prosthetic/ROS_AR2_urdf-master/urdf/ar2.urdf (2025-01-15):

<robot name="ar2">
  <link name="base_link">
    <inertial>
      <origin xyz="-4.6941E-06 0.054174 0.038824" rpy="0 0 0" />
      <mass value="0.7102" />
      <inertia ixx="0.0039943" ixy="3.697E-07" ixz="-5.7364E-08" iyy="0.0014946" iyz="-0.00036051" izz="0.0042554" />
    </inertial>
    <visual>
      <origin xyz="0 0 0" rpy="0 0 0" />
      <geometry>
        <mesh filename="package://ar2/meshes/base_link.STL" />
      </geometry>
      <material name="">
        <color rgba="1 1 0 1" />
      </material>
    </visual>
    <collision>
      <origin xyz="0 0 0" rpy="0 0 0" />
      <geometry>
        <mesh filename="package://ar2/meshes/base_link.STL" />
      </geometry>
    </collision>
  </link>
  <link name="link_1">
    <inertial>
      <origin xyz="-0.022706 0.04294 -0.12205" rpy="0 0 0" />
      <mass value="0.88065" />
      <inertia ixx="0.0034" ixy="0.00042296" ixz="-0.00089231" iyy="0.0041778" iyz="0.0010848" izz="0.0027077" />
    </inertial>
    <visual>
      <origin xyz="0 0 0" rpy="0 0 0" />
      <geometry>
        <mesh filename="package://ar2/meshes/link_1.STL" />
      </geometry>
      <material name="">
        <color rgba="1 1 0 1" />
      </material>
    </visual>
    <collision>
      <origin xyz="0 0 0" rpy="0 0 0" />
      <geometry>
        <mesh filename="package://ar2/meshes/link_1.STL" />
      </geometry>
    </collision>
  </link>
  <joint name="joint_1" type="continuous">
    <origin xyz="0 0 0.003445" rpy="3.1416 -1.0248E-21 -1.6736E-05" />
    <parent link="base_link" />
    <child link="link_1" />
    <axis xyz="0 0 1" />
  </joint>
  <link name="link_2">
    <inertial>
      <origin xyz="0.064818 -0.11189 -0.038671" rpy="0 0 0" />
      <mass value="0.57738" />
      <inertia ixx="0.0047312" ixy="0.0022624" ixz="0.00032144" iyy="0.0020836" iyz="-0.00056569" izz="0.0056129" />
    </inertial>
    <visual>
      <origin xyz="0 0 0" rpy="0 0 0" />
      <geometry>
        <mesh filename="package://ar2/meshes/link_2.STL" />
      </geometry>
      <material name="">
        <color rgba="1 1 0 1" />
      </material>
    </visual>
    <collision>
      <origin xyz="0 0 0" rpy="0 0 0" />
      <geometry>
        <mesh filename="package://ar2/meshes/link_2.STL" />
      </geometry>
    </collision>
  </link>
  <joint name="joint_2" type="continuous">
    <origin xyz="0 0.064146 -0.16608" rpy="1.5708 0.5236 -1.5708" />
    <parent link="link_1" />
    <child link="link_2" />
    <axis xyz="0 0 1" />
  </joint>
  <link name="link_3">
    <inertial>
      <origin xyz="-0.00029765 -0.023661 -0.0019125" rpy="0 0 0" />
      <mass value="0.1787" />
      <inertia ixx="0.0001685" ixy="-2.7713E-05" ixz="5.6885E-06" iyy="0.00012865" iyz="2.9256E-05" izz="0.00020744" />
    </inertial>
    <visual>
      <origin xyz="0 0 0" rpy="0 0 0" />
      <geometry>
        <mesh filename="package://ar2/meshes/link_3.STL" />
      </geometry>
      <material name="">
        <color rgba="1 1 0 1" />
      </material>
    </visual>
    <collision>
      <origin xyz="0 0 0" rpy="0 0 0" />
      <geometry>
        <mesh filename="package://ar2/meshes/link_3.STL" />
      </geometry>
    </collision>
  </link>
  <joint name="joint_3" type="continuous">
    <origin xyz="0.1525 -0.26414 0" rpy="3.3431E-16 -1.4164E-16 -2.618" />
    <parent link="link_2" />
    <child link="link_3" />
    <axis xyz="0 0 -1" />
  </joint>
  <link name="link_4">
    <inertial>
      <origin xyz="-0.0016798 -0.00057319 -0.074404" rpy="0 0 0" />
      <mass value="0.34936" />
      <inertia ixx="0.0030532" ixy="-1.8615E-05" ixz="-7.0047E-05" iyy="0.0031033" iyz="-2.3301E-05" izz="0.00022264" />
    </inertial>
    <visual>
      <origin xyz="0 0 0" rpy="0 0 0" />
      <geometry>
        <mesh filename="package://ar2/meshes/link_4.STL" />
      </geometry>
      <material name="">
        <color rgba="1 1 0 1" />
      </material>
    </visual>
    <collision>
      <origin xyz="0 0 0" rpy="0 0 0" />
      <geometry>
        <mesh filename="package://ar2/meshes/link_4.STL" />
      </geometry>
    </collision>
  </link>
  <joint name="joint_4" type="continuous">
    <origin xyz="0 0 0.00675" rpy="1.5708 -1.2554 -1.5708" />
    <parent link="link_3" />
    <child link="link_4" />
    <axis xyz="0 0 -1" />
  </joint>
  <link name="link_5">
    <inertial>
      <origin xyz="0.0015066 -1.3102E-05 -0.012585" rpy="0 0 0" />
      <mass value="0.11562" />
      <inertia ixx="5.5035E-05" ixy="-1.019E-08" ixz="-2.6243E-06" iyy="8.2921E-05" iyz="1.4437E-08" izz="5.2518E-05" />
    </inertial>
    <visual>
      <origin xyz="0 0 0" rpy="0 0 0" />
      <geometry>
        <mesh filename="package://ar2/meshes/link_5.STL" />
      </geometry>
      <material name="">
        <color rgba="1 1 0 1" />
      </material>
    </visual>
    <collision>
      <origin xyz="0 0 0" rpy="0 0 0" />
      <geometry>
        <mesh filename="package://ar2/meshes/link_5.STL" />
      </geometry>
    </collision>
  </link>
  <joint name="joint_5" type="continuous">
    <origin xyz="0 0 -0.22225" rpy="3.1416 0 -2.8262" />
    <parent link="link_4" />
    <child link="link_5" />
    <axis xyz="-1 0 0" />
  </joint>
  <link name="link_6">
    <inertial>
      <origin xyz="2.9287E-10 -1.6472E-09 0.0091432" rpy="0 0 0" />
      <mass value="0.013863" />
      <inertia ixx="1.3596E-06" ixy="3.0585E-13" ixz="5.7102E-14" iyy="1.7157E-06" iyz="6.3369E-09" izz="2.4332E-06" />
    </inertial>
    <visual>
      <origin xyz="0 0 0" rpy="0 0 0" />
      <geometry>
        <mesh filename="package://ar2/meshes/link_6.STL" />
      </geometry>
      <material name="">
        <color rgba="1 1 0 1" />
      </material>
    </visual>
    <collision>
      <origin xyz="0 0 0" rpy="0 0 0" />
      <geometry>
        <mesh filename="package://ar2/meshes/link_6.STL" />
      </geometry>
    </collision>
  </link>
  <joint name="joint_6" type="continuous">
    <origin xyz="-0.000294 0 0.02117" rpy="0 0 3.1416" />
    <parent link="link_5" />
    <child link="link_6" />
    <axis xyz="0 0 -1" />
  </joint>
</robot>

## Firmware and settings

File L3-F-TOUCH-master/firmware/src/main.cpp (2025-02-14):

#include "main.h"
#include "wifikeys.h"

#define OTA

//config sensor role
#define ROLE FINGER

#define FINGER 0
#define THUMB_PALM 1
#define TRI_PALM 2
#define DOUBLE_PALM_BOT 3
#define DOUBLE_PALM_TOP 4

const int shutterTime[]={1,110,50,20,20};//finger default is 8,thumb_palm,tri_palm 350,double_palm
/** Camera class */
OV2640 cam;
boolean ota=false;

camera_config_t userCamNew {

    .pin_pwdn = 19, //NC
    .pin_reset = -1,//NC

    .pin_xclk = 0,//MCLK

    .pin_sscb_sda = 8,//TWI SDA
    .pin_sscb_scl = 7,//TWI SCK

    // Note: LED GPIO is apparently 4 not sure where that goes
    // per https://github.com/donny681/ESP32_CAMERA_QR/blob/e4ef44549876457cd841f33a0892c82a71f35358/main/led.c
    .pin_d7 = 15,
    .pin_d6 = 13,
    .pin_d5 = 12,
    .pin_d4 = 27,
    .pin_d3 = 25,
    .pin_d2 = 32,
    .pin_d1 = 33,
    .pin_d0 = 26,
    .pin_vsync = 4,
    .pin_href = 2,//HSYNC
    .pin_pclk = 14,
    .xclk_freq_hz = 24000000, //24000000
    .ledc_timer = LEDC_TIMER_1,
    .ledc_channel = LEDC_CHANNEL_1,


#ifdef USE_PNG
	.pixel_format = PIXFORMAT_RGB565,	
#if ROLE
	.frame_size = FRAMESIZE_VGA,
#else
    .frame_size = FRAMESIZE_VGA,
#endif

#else
	 .pixel_format = PIXFORMAT_JPEG,

#ifdef ENABLE_RTSPSERVER
#if ROLE
	.frame_size = FRAMESIZE_HQVGA,	
#else
    .frame_size = FRAMESIZE_QCIF,
#endif

#else // ENABLE_WEBSERVER
#if ROLE
	.frame_size = FRAMESIZE_HQVGA,
#else
    .frame_size = FRAMESIZE_QCIF,
#endif

#endif
#endif


#ifdef ENABLE_WEBSERVER	
    .jpeg_quality = 3,             //0-63 lower numbers are higher quality	10
    .fb_count = 1 // if more than one i2s runs in continous mode.  Use only with jpeg
#else //enable rtspserver
	.jpeg_quality = 10,             //0-63 lower numbers are higher quality	10
    .fb_count = 2 // if more than one i2s runs in continous mode.  Use only with jpeg
#endif

};

camera_config_t test {

    .pin_pwdn = 32,
    .pin_reset = -1,

    .pin_xclk = 0,

    .pin_sscb_sda = 26,
    .pin_sscb_scl = 27,

    // Note: LED GPIO is apparently 4 not sure where that goes
    // per https://github.com/donny681/ESP32_CAMERA_QR/blob/e4ef44549876457cd841f33a0892c82a71f35358/main/led.c
    .pin_d7 = 35,
    .pin_d6 = 34,
    .pin_d5 = 39,
    .pin_d4 = 36,
    .pin_d3 = 21,
    .pin_d2 = 19,
    .pin_d1 = 18,
    .pin_d0 = 5,
    .pin_vsync = 25,
    .pin_href = 23,
    .pin_pclk = 22,
    .xclk_freq_hz = 24000000,
    .ledc_timer = LEDC_TIMER_1,
    .ledc_channel = LEDC_CHANNEL_1,
    .pixel_format = PIXFORMAT_JPEG,
    // .frame_size = FRAMESIZE_UXGA, // needs 234K of framebuffer space
    // .frame_size = FRAMESIZE_SXGA, // needs 160K for framebuffer
    // .frame_size = FRAMESIZE_VGA, // needs 96K or even smaller FRAMESIZE_SVGA - can work if using only 1 fb
    // .frame_size = FRAMESIZE_QCIF,
 .frame_size = FRAMESIZE_VGA,
    .jpeg_quality = 10,               //0-63 lower numbers are higher quality
    .fb_count = 2 // if more than one i2s runs in continous mode.  Use only with jpeg
};


void setup()
{
	// Start the serial connection
	Serial.begin(115200);

	Serial.println("\n\n##################################");
	Serial.printf("Internal Total heap %d, internal Free Heap %d\n", ESP.getHeapSize(), ESP.getFreeHeap());
	Serial.printf("SPIRam Total heap %d, SPIRam Free Heap %d\n", ESP.getPsramSize(), ESP.getFreePsram());
	Serial.printf("ChipRevision %d, Cpu Freq %d, SDK Version %s\n", ESP.getChipRevision(), ESP.getCpuFreqMHz(), ESP.getSdkVersion());
	Serial.printf("Flash Size %d, Flash Speed %d\n", ESP.getFlashChipSize(), ESP.getFlashChipSpeed());
	Serial.println("##################################\n\n");

	
	delay(100);
	
	
	cam.init(userCamNew);
	delay(100);

	sensor_t * s = esp_camera_sensor_get();
  	// s->set_wb_mode(s, 1);//enable manul WB as sunny
    // s->set_exposure_ctrl(s,0);//enable manul shutter 
    // s->set_saturation(s, 1);  
	// // s->set_sharpness(s, 2);
	// s->set_aec_value(s,shutterTime[ROLE]);//shutter time

    //try adjust WB (seems RGB)
    // s->set_reg(s,0XCC,0xFF,0x52);//R default:0x50 3.50:0x48 3.53:0x48 3.61:0x52 3.60:0x55 3.59:0x48 3.56:0x54 3.68:0x50 3.55:0x53 3.58:0x54 3.63:0x50 3.52:0x54 3.54:0x52 3.62  3.66:0x50 3.51:0x48 3.53:0x52 3.57:0x52 3.61 0x48 3.65:0x48
    // s->set_reg(s,0XCD,0xFF,0x45);//G default:0x41 3.50:0x45 3.53:0x41 3.61:0x45 3.60:0x45 3.59:0x45 3.56:0x45 3.68:0x41 3.55:0x42 3.58:0x44 3.63:0x48 3.52:0x45 3.54:0x41 3.62  3.66:0x45 3.51:0x41 3.53:0x41 3.57:0x45 3.61 0x45 3.65:0x41
    // s->set_reg(s,0XCE,0xFF,0x50);//B default:0x54 3.50:0x52 3.53:0x50 3.61:0x50 3.60:0x54 3.59:0x52 3.56:0x54 3.68:0x42 3.55:0x54 3.58:0x54 3.63:0x52 3.52:0x54 3.54:0x52 3.62  3.66:0x52 3.51:0x50 3.53:0x52 3.57:0x48 3.61 0x52 3.65:0x50

	//top finger default RGB : 0x52 0x45 0x50
	//middle finger default RGB : 0x50 0x42 0x52
	//bottom finger default RGB : 0x46 0x42 0x48
	//TRI_PALM default: 0x46 0x42 0x48

	// Connect the WiFi
    Serial.println("Wifi init start");
	WiFi.mode(WIFI_STA);
	WiFi.begin(ssid, password);
	//WiFi.setTxPower(WIFI_POWER_8_5dBm);
	Serial.println("TX Power: "+String(WiFi.getTxPower()));

	while (WiFi.status() != WL_CONNECTED)
	{
		delay(500);
		Serial.print(".");
	}
	// Print information how to contact the camera server
	IPAddress ip = WiFi.localIP();
	Serial.print("\nWiFi connected with IP ");
	Serial.println(ip);


#ifdef ENABLE_RTSPSERVER
	Serial.print("Stream Link: rtsp://");
	Serial.print(ip);
	Serial.println(":8554/mjpeg/1\n");
	// Initialize the RTSP stream server
	initRTSP();
#endif
#ifdef ENABLE_WEBSERVER
	Serial.print("Browser Stream Link: http://");
	Serial.print(ip);
	Serial.println("\n");
	Serial.print("Browser Single Picture Link: http://");
	Serial.print(ip);
	Serial.println("/jpg\n");
	// Initialize the HTTP web stream server
	initWebStream();
#endif
#ifdef ENABLE_UDPRAW
	Serial.println("Broadcast via UDP, to port 8888");
	initUDPraw();
#endif
#ifdef USE_PNG
	initEncoder();
	s->set_reg(s,0XDA,0x01,0x01); //change high byte first/low byte first of RGB565 data
#endif

	//use RX PIN for OTA 
	pinMode(3,INPUT_PULLUP);
}

void loop()
{	
#ifdef OTA

	if(digitalRead(3)==LOW){
		for(int i=0;i<10;i++){
			if (digitalRead(3)==HIGH) return;
			delay(1);
		}
		ota=true;
		#ifdef ENABLE_RTSPSERVER
		stopRTSP();
		#endif
		#ifdef ENABLE_WEBSERVER
		stopWebStream();
		#endif

		ArduinoOTA
		.onStart([]() {
		String type;
		if (ArduinoOTA.getCommand() == U_FLASH)
			type = "sketch";
		else // U_SPIFFS
			type = "filesystem";

		// NOTE: if updating SPIFFS this would be the place to unmount SPIFFS using SPIFFS.end()
		Serial.println("Start updating " + type);
		})
		.onEnd([]() {
		Serial.println("\nEnd");
		})
		.onProgress([](unsigned int progress, unsigned int total) {
		Serial.printf("Progress: %u%%\r", (progress / (total / 100)));
		})
		.onError([](ota_error_t error) {
		Serial.printf("Error[%u]: ", error);
		if (error == OTA_AUTH_ERROR) Serial.println("Auth Failed");
		else if (error == OTA_BEGIN_ERROR) Serial.println("Begin Failed");
		else if (error == OTA_CONNECT_ERROR) Serial.println("Connect Failed");
		else if (error == OTA_RECEIVE_ERROR) Serial.println("Receive Failed");
		else if (error == OTA_END_ERROR) Serial.println("End Failed");
		});
		ArduinoOTA.begin();
		ArduinoOTA.setTimeout(5000);

	}
	if(ota)
		ArduinoOTA.handle();
#endif

	delay(10);
}

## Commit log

2025-01-15 Added Current Solidworks model
    [1100mAh lipo v8.SLDPRT, Assem1.SLDASM, Assem2.SLDASM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]
2025-02-14 Gel Touch Sensor for sensor feedback
    https://github.com/wangmeng13thu/L3-F-TOUCH/tree/master?tab=readme-ov-file
    [Acrylicsheet.stl, Bottom1.stl, Bottom2.stl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]
2026-08-26 Add Simulation/: the Newton physics-sim line for the hand
    The simulation work the README promised as "upcoming", delivered and
    verified: the hand as a full articulated Newton model (8 spring palm
    bones, 3 closed loops, 22 finger DOFs, self-colliding CoACD shells),
    15-pad tactile sensing, the Franka-mounted reach/grasp/lift demo with
    its honest REAL-GRASP gate, the GPU-batched in-hand reorientation RL
    env (validated N=8192, 0.0% divergence, ~47k env-steps/s on one RTX
    5090), a self-contained PPO trainer, the NaN-localization stress
    harness, and the batched-GPU weld calibrator.
    Ported from the private research tree with paths de-hardcoded to the
    in-repo Simulation/assets (hand CAD as USD + Sh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
2026-08-26 Simulation: add the grasp-demo recording (GIF + mp4 + still), embed in READMEs
    Palm-side take of flexpalm_arm_demo.py --arm franka: reach, whole-hand
    grasp, lift — the flexible palm bones and 15 tactile pads visible as the
    hand conforms around the cube and carries it off the pedestal. Recorded
    live from the committed demo on newton 1.4.0 / RTX 5090 (120 frames,
    stride 3, 30 fps).
    Claude-Session: https://claude.ai/code/session_01UmRkfo9LTGGMtJ7ZZ8XcVA
